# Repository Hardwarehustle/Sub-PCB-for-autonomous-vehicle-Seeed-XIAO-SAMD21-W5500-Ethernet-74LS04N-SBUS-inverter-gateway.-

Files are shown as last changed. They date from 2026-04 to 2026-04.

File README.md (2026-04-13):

# 🤖 Autonomous Vehicle — Sub Control Board (OW_Sub_Seed_PCB)

> **Designed by:** Janardhan BV  
> **Tool:** KiCad EDA 9.0.7  
> **File:** `OW_SUB_SEED_SCH.kicad_sch`  
> **MCU:** Seeed XIAO SAMD21 (ARM Cortex-M0+, 48 MHz)  
> **Type:** Sub PCB — Ethernet + SBUS Gateway Board  
> **Parent Project:** Autonomous Wheeled Vehicle (OW_Main_PCB)

---

## 📌 Project Overview

This is the **Sub Control Board** of the Autonomous Wheeled Vehicle project, designed to act as a dedicated **Ethernet ↔ SBUS communication gateway**. A full STM32 Nucleo F446RE, this sub PCB uses the compact **Seeed XIAO SAMD21** (ARM Cortex-M0+) to handle a focused task: receiving commands over **W5500 Ethernet (TCP/IP)** and forwarding them as an **inverted SBUS UART signal** (via 74LS04N hex inverter) to RC/motor control receivers.

The board features:
- **Seeed XIAO SAMD21** as the lightweight edge MCU
- **W5500** hardwired TCP/IP Ethernet controller (SPI 3.3V)
- **74LS04N Hex Inverter** for SBUS signal logic inversion
- **XT30 connector** for 5V input power
- **Molex 4-pin output** for SBUS signal to downstream devices
- Compact square form factor with **4× corner mounting holes**

---

## 🖼️ Project Visuals

### Schematic
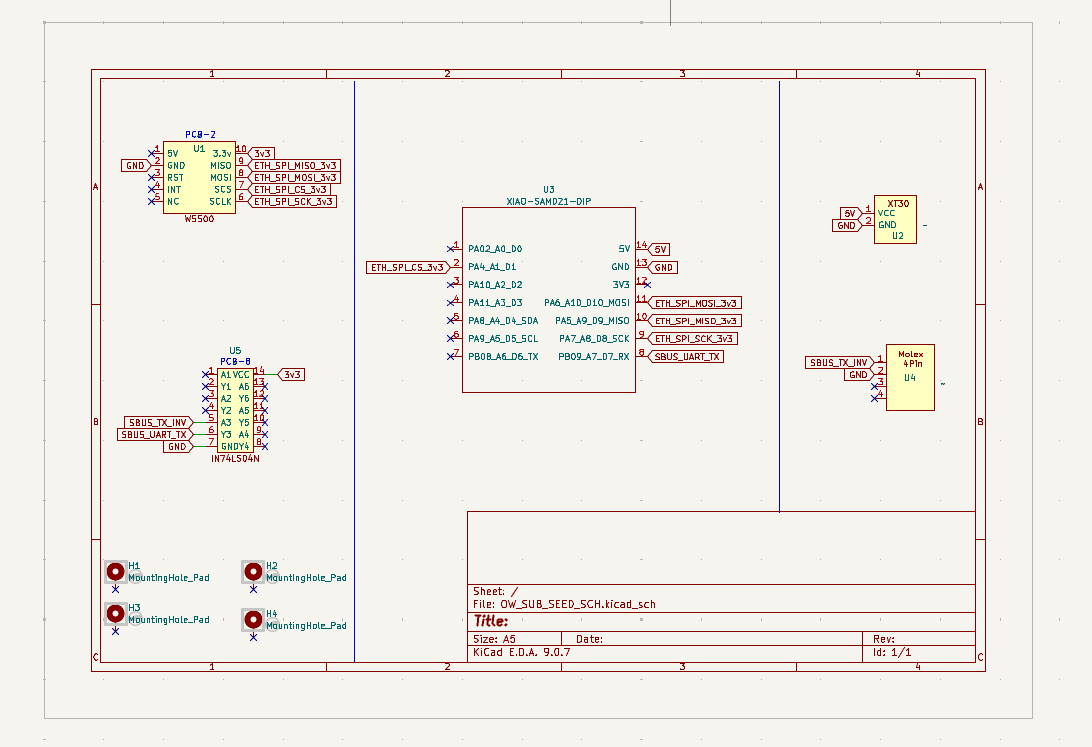
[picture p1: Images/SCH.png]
Schematic


### PCB Layout
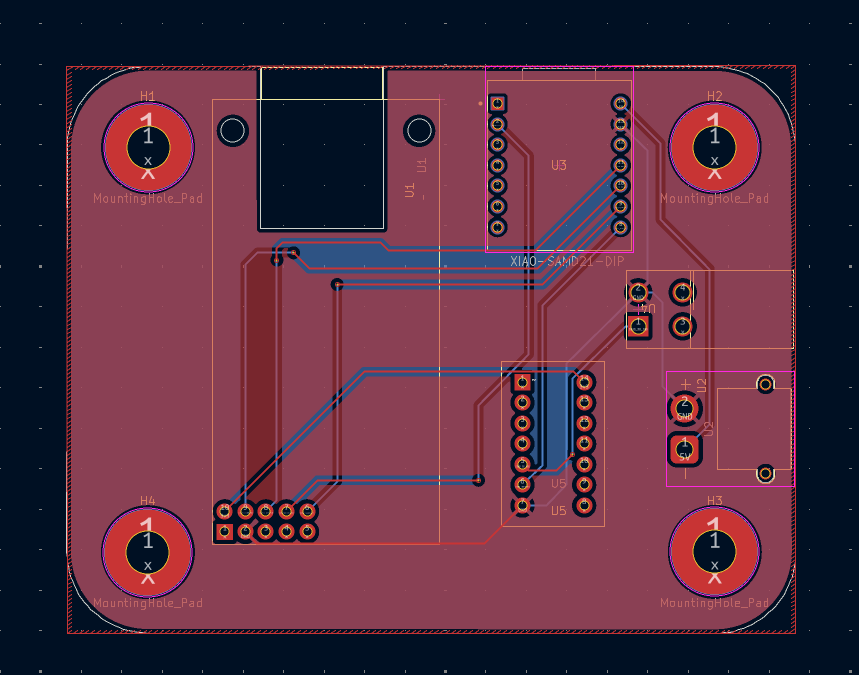
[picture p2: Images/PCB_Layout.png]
PCB Layout


### 3D Board Top View
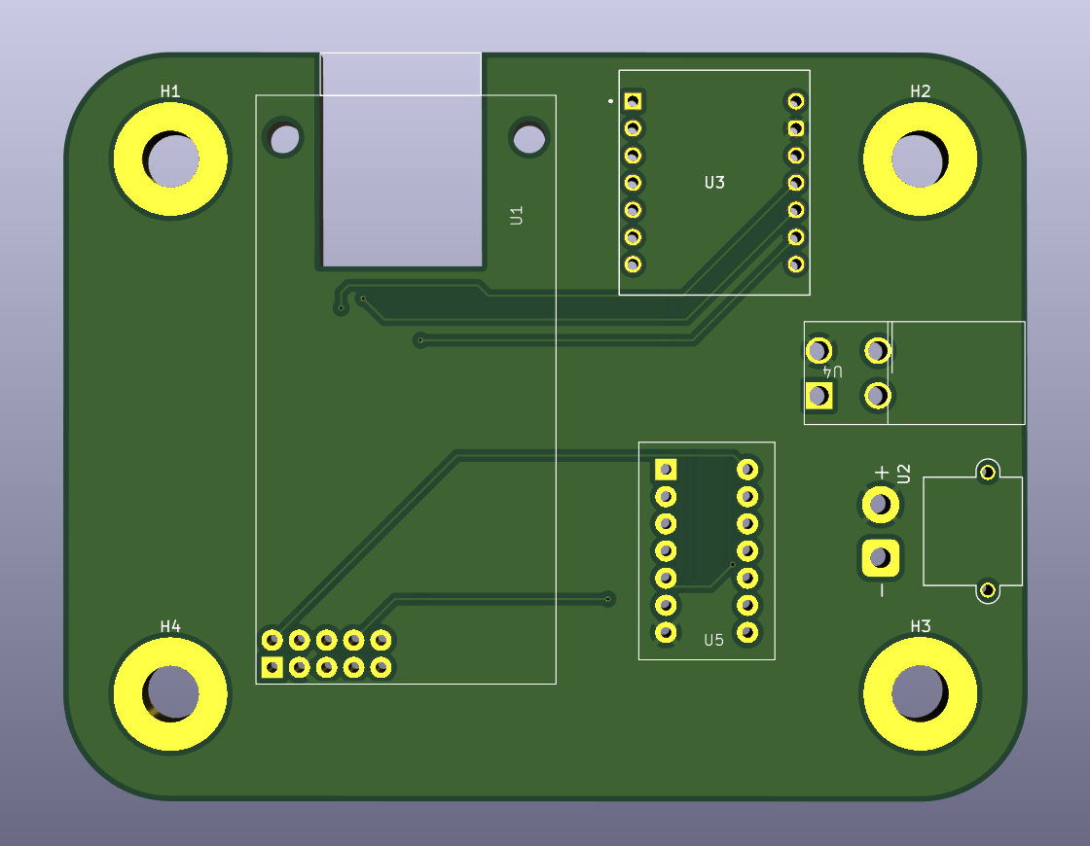
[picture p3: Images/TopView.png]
3D Top View


### 3D Board Bottom View
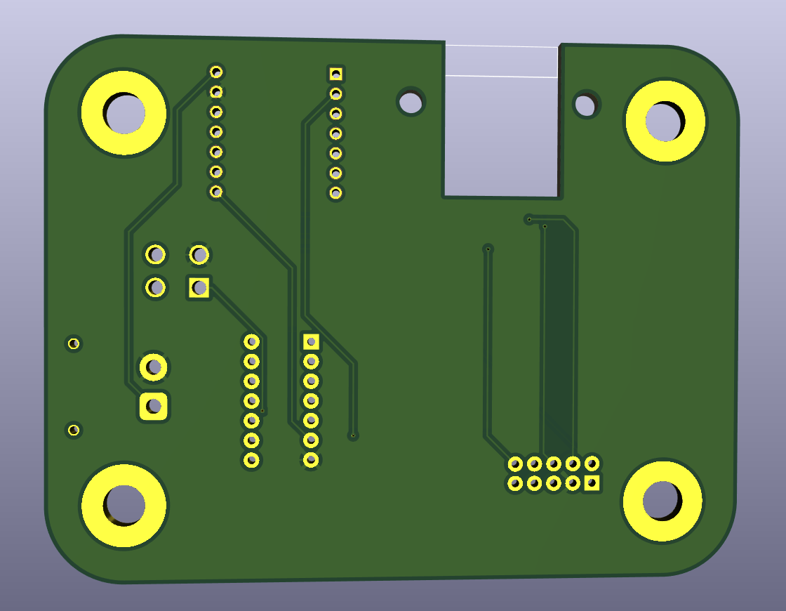
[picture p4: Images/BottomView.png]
3D Bottom View


---

## 🏗️ System Architecture

```
5V Input (XT30 — U2)
      │
      ├──► XIAO SAMD21 (U3) ◄──── USB-C (onboard programming)
      │          │
      │     SPI (3.3V)
      │          │
      └──► W5500 Ethernet (U1)
                 │
          TCP/IP Network ──► Command packets from Main Board / PC
                 │
          XIAO SAMD21 decodes command
                 │
          UART TX (SBUS data — inverted logic required)
                 │
          74LS04N (U5) — Signal Inversion
                 │
          SBUS_UART_TX ──► Molex 4-pin (U4) ──► RC/Motor Receiver
```

---

## 📊 Component BOM

| Ref | Component | Part | Function |
|:---:|:---|:---|:---|
| U3 | MCU | Seeed XIAO SAMD21 (DIP footprint) | Main microcontroller (Cortex-M0+, 48 MHz) |
| U1 | Ethernet Controller | W5500 (PCB-2 module) | SPI hardwired TCP/IP Ethernet |
| U5 | Hex Inverter | 74LS04N (DIP-14) | SBUS UART signal logic inversion |
| U2 | Power Connector | XT30 | 5V input power |
| U4 | Output Connector | Molex 4-pin | SBUS output + GND |
| H1–H4 | Mounting Holes | MountingHole_Pad | 4× PCB corner mounting |

---

## 🔌 Pin Assignment — XIAO SAMD21 (U3)

| XIAO Pin | Signal Name | Function |
|:---:|:---|:---|
| PA02 / A0 / D0 | GPIO | General purpose I/O |
| PA4 / A1 / D1 | GPIO | General purpose I/O |
| PA10 / A2 / D2 | GPIO | General purpose I/O |
| PA11 / A3 / D3 | GPIO | General purpose I/O |
| PA8 / A4 / D4 / SDA | I2C SDA | I2C data |
| PA9 / A5 / D5 / SCL | I2C SCL | I2C clock |
| PB08 / A6 / D6 / TX | UART TX | SBUS UART transmit → 74LS04N |
| PA6 / A1D / D10 / MOSI | SPI MOSI | W5500 SPI MOSI |
| PA5 / A9 / D9 / MISO | SPI MISO | W5500 SPI MISO |
| PA7 / A8 / D8 / SCK | SPI SCK | W5500 SPI clock |
| PB09 / A7 / D7 / RX | UART RX | UART receive |
| 5V | Power | 5V input from XT30 |
| 3V3 | Power | 3.3V output to W5500 |
| GND | Ground | Common ground |

---

## 🌐 W5500 Ethernet Controller (U1)

| W5500 Pin | Connected Net | XIAO Pin |
|:---:|:---|:---:|
| MISO | ETH_SPI_MISO_3v3 | PA5 / D9 |
| MOSI | ETH_SPI_MOSI_3v3 | PA6 / D10 |
| SCS | ETH_SPI_CS_3v3 | PA11 / D3 |
| SCLK | ETH_SPI_SCK_3v3 | PA7 / D8 |
| RST | ETH Reset | GPIO |
| INT | ETH Interrupt | GPIO |
| VCC | 5V | XT30 |
| 3.3V | 3v3 | XIAO 3V3 |

The W5500 provides a **full hardwired TCP/IP stack** (TCP, UDP, IPv4, ARP, ICMP) over SPI, supporting up to **8 simultaneous sockets** with 32KB internal buffer — enabling this sub-board to receive control commands from the main vehicle computer or a remote PC over Ethernet.

---

## 📡 SBUS Signal — 74LS04N Inverter (U5)

**SBUS** (Serial Bus) is a digital RC protocol used by Futaba and FrSky receivers. It uses **inverted UART** at 100,000 baud (100kbps), 8E2 format. Since the XIAO SAMD21 outputs standard logic-level UART (non-inverted), the **74LS04N hex inverter** flips the signal:

```
XIAO UART TX (D6/PB08)
      │
      └──► 74LS04N Input (A1) ──► Output (Y1) ──► SBUS_UART_TX
                 (Logic Inversion: HIGH→LOW, LOW→HIGH)
                      │
               SBUS_TX_INV net → Molex 4-pin (U4)
```

**SBUS Protocol Parameters:**
- Baud rate: 100,000 bps
- Format: 8 bits, Even parity, 2 stop bits (8E2)
- Logic: Inverted (idle = LOW, start bit = HIGH)
- Frame: 25 bytes, 16 channels, 2 flags

---

## 🔋 Power Architecture

```
XT30 (U2) — 5V Input
   ├──► XIAO SAMD21 VCC (5V pin)
   │         └──► XIAO internal 3.3V LDO ──► 3v3 net
   └──► W5500 VCC (5V)
              └──► W5500 internal 3.3V reg ──► W5500 core
```

---

## 📐 PCB Design Highlights

- **EDA Tool:** KiCad EDA 9.0.7
- **File:** `OW_SUB_SEED_SCH.kicad_sch`
- **Board Shape:** Compact square with rounded corners
- **Mounting:** 4× corner mounting holes (H1–H4) for chassis mount
- **XIAO SAMD21 (U3):** Piggyback mount on dual-row female header footprint
- **W5500 (U1):** Module footprint top-left, close to XIAO SPI pins
- **74LS04N (U5):** DIP-14 IC socket, centrally placed for easy replacement
- **XT30 (U2):** Right-side edge for easy cable routing
- **Molex 4-pin (U4):** Right-side, close to SBUS output target

---

## 🔗 Relationship to Main Control Board

| Feature | Main Board (OW_Main_PCB) | Sub Board (OW_Sub_Seed_PCB) |
|:---|:---:|:---:|
| MCU | STM32 Nucleo F446RE (180 MHz) | Seeed XIAO SAMD21 (48 MHz) |
| Ethernet | W5500 (SPI) | W5500 (SPI) |
| RS-485 | MAX485 | ✗ |
| SBUS Output | ✗ | 74LS04N + UART |
| Relays | 2× G5LE-1 | ✗ |
| PWM Ports | 4× | ✗ |
| Power Input | 12V (XT30) | 5V (XT30) |
| Board Size | Large (chassis mount) | Small (compact sub-board) |
| KiCad File | `Ow_main_pcb.kicad_sch` | `OW_SUB_SEED_SCH.kicad_sch` |

---

## 🧪 Bring-Up & Testing

### Step 1 — Power Check
- Apply 5V via XT30 (U2)
- Measure 3.3V at W5500 VCC and XIAO 3V3 pin
- Idle current: ~80–120 mA (XIAO + W5500)

### Step 2 — XIAO SAMD21 Programming
- Connect USB-C cable to XIAO SAMD21
- Board appears as **COM port / /dev/ttyACM0**
- Upload sketch via Arduino IDE (select **Seeed XIAO SAMD21**)

### Step 3 — Ethernet Test
- Connect RJ45 to W5500 module
- Ping board IP from PC
- Send UDP/TCP test packet and verify receipt by XIAO

### Step 4 — SBUS Inversion Test
- Program XIAO to output SBUS frame at 100kbps 8E2
- Probe XIAO TX (D6) — should show **normal UART** (idle HIGH)
- Probe 74LS04N output (SBUS_UART_TX) — should show **inverted UART** (idle LOW)
- Connect to RC receiver — verify 16 SBUS channels decoded correctly

---

## 🖥️ Firmware (Arduino / XIAO SAMD21)

```cpp
// Required Libraries
#include <SPI.h>              // W5500 SPI
#include <Ethernet.h>         // WIZnet W5500 Ethernet library
// or use: Ethernet2.h / WIZ5500 HAL

// SBUS output via Serial1 (PB08 = D6)
// 100000 baud, 8E2, inverted by 74LS04N hardware

void setup() {
  Serial1.begin(100000, SERIAL_8E2);  // SBUS baud
  Ethernet.begin(mac, ip);            // W5500 init
}

void loop() {
  // Receive commands over Ethernet
  // Parse → encode SBUS frame
  // Transmit via Serial1 → 74LS04N → SBUS output
}
```

---

## 📁 Repository Structure

```
AV-Sub-Seed-PCB/
├── images/
│   ├── SCH.jpg               ← KiCad schematic export
│   └── TopView.jpg           ← 3D board render
├── KiCad/
│   ├── OW_SUB_SEED_SCH.kicad_sch   ← Schematic source
│   ├── OW_SUB_SEED.kicad_pcb       ← PCB layout source
│   └── OW_SUB_SEED.kicad_pro       ← Project file
├── Gerber/
│   └── (Gerber + drill files)
├── Firmware/
│   └── ow_sub_seed_fw/
│       └── ow_sub_seed_fw.ino
└── README.md
```

---

## 🏷️ GitHub Topics to Add

```
autonomous-vehicle  xiao-samd21  seeed  w5500  ethernet
sbus  rc-protocol  74ls04n  signal-inversion  kicad
pcb-design  embedded-systems  robotics  cortex-m0
```

---

## ⚠️ Design Notes & Cautions

- **74LS04N supply is 5V** — ensure VCC of 74LS04N is connected to 5V, not 3.3V, for proper TTL output swing
- **SBUS baud rate is exactly 100,000 bps** — XIAO SAMD21 `Serial1.begin(100000, SERIAL_8E2)` must be used; standard 115200 will not work
- **W5500 is 3.3V logic** — XIAO SAMD21 is 3.3V native, no level shifting needed on SPI lines
- **XT30 is 5V input** — do not apply 12V; this sub-board is 5V-only unlike the main board which is 12V
- **74LS04N DIP-14** — socketed for easy replacement; verify pin 7 (GND) and pin 14 (VCC) before powering

---

## 📄 License

This project is open for educational and personal use.  
© 2025 Janardhan BV — All rights reserved.

---

## 🙋 Author

**Janardhan BV**  
Embedded Hardware Engineer | PCB Design | Power Electronics  
📍 Bengaluru, India

---
*Designed in KiCad EDA 9.0.7 | XIAO SAMD21 Ethernet-to-SBUS Sub PCB — Autonomous Vehicle*

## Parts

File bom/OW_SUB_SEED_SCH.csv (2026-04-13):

Id | Designator | Footprint | Quantity | Designation | Supplier and ref
1 | U2 | AMASS_XT30PW-M_1x02_P2.50mm_Horizontal | 1 | ~
2 | U5 | IN74LS04N | 1 | ~
3 | U3 | MODULE_102010388 | 1 | XIAO-SAMD21-DIP
4 | U4 | Molex_2x2_4.2mm | 1 | ~
5 | U1 | W5500 | 1 | ~

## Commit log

2026-04-13 Revise README for Autonomous Vehicle Sub Control Board
    Updated README to provide detailed project information, including overview, system architecture, component BOM, pin assignments, and testing procedures.
2026-04-13 Revise project visuals in README
    Updated image paths and added new visuals for PCB layout and 3D views.
